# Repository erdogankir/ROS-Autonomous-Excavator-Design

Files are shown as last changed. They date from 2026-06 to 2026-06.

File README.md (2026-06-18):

# Teleoperation-Assisted Autonomous Excavator Design & Modeling 🚜🤖

This repository contains the complete conceptual design, kinematic modeling, ROS-based autonomous algorithms, and embedded systems architecture for a teleoperation-assisted autonomous excavator.

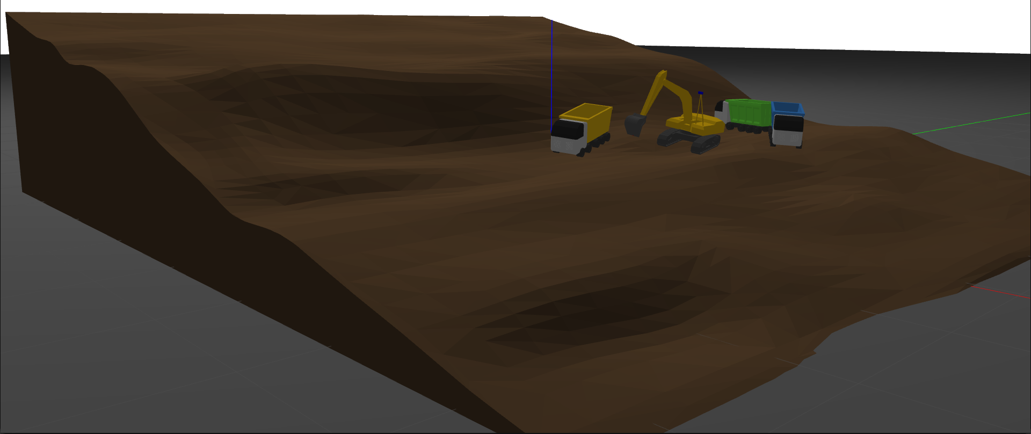
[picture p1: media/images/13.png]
Gazebo Terrain & Target Truck


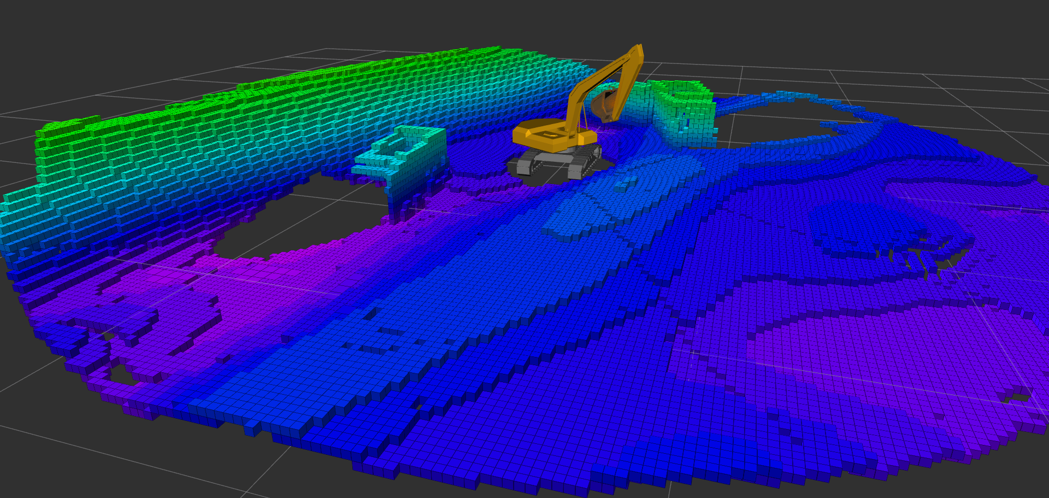
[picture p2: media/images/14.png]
RViz OctoMap Volumetric Mapping


## 🎯 Project Overview
In industries with harsh and hazardous environments like mining and construction, minimizing human exposure while maximizing operational efficiency is a critical engineering challenge. This project aims to transform traditional heavy machinery into smart, situational-aware systems. By developing a digital twin of a CAT 349E excavator, the system achieved an 84% operational success rate in end-to-end autonomous dig-and-load cycles across 100 simulation trials. 

## ⚙️ Technical Specifications
* **Simulation Environment:** ROS Noetic & Gazebo (ODE Physics Engine)
* **Base Model:** 1:10 scaled Caterpillar 349E excavator
* **Perception:** Dual RGB-D Depth Cameras (640x480 VGA, 10Hz)
* **Hardware Prototyping:** Dual-Core ESP32 microcontroller with PCA9685 PWM driver and DRV8833 H-Bridges
* **Actuators:** N20 DC Gearmotors (50 RPM for torque, 1000 RPM for linear actuators)
* **Power Management:** 7.4V 2S Li-ion battery (2450 mAh) managed by a 13A BMS

## 🔬 Engineering Methodology & Algorithms
All simulation and autonomous control phases were executed using **ROS Noetic**, while the physical prototype was driven by custom C++ embedded firmware. The engineering workflow includes:

1. **Kinematic Modeling:** The 4-DOF manipulator (swing, boom, arm, bucket) was mapped using URDF. Inverse kinematics were solved numerically via the MoveIt! framework and KDL library to avoid singularity states.
2. **3D Perception & Mapping:** Point Cloud data from RGB-D sensors were converted into volumetric maps using the OctoMap algorithm to scan dynamic terrains.
3. **Computer Vision:** Target truck localization was achieved dynamically using HSV color space masking and image moments via OpenCV.
4. **Trajectory Generation:** To eliminate mechanical jerks during operations, a custom Cosine Interpolation (S-Curve) motor was developed for smooth acceleration.
5. **Hardware Proof of Concept:** A 6-axis open-loop physical prototype was manufactured, featuring low-latency teleoperation controlled by a Sony DualSense gamepad over Wi-Fi/Bluetooth.

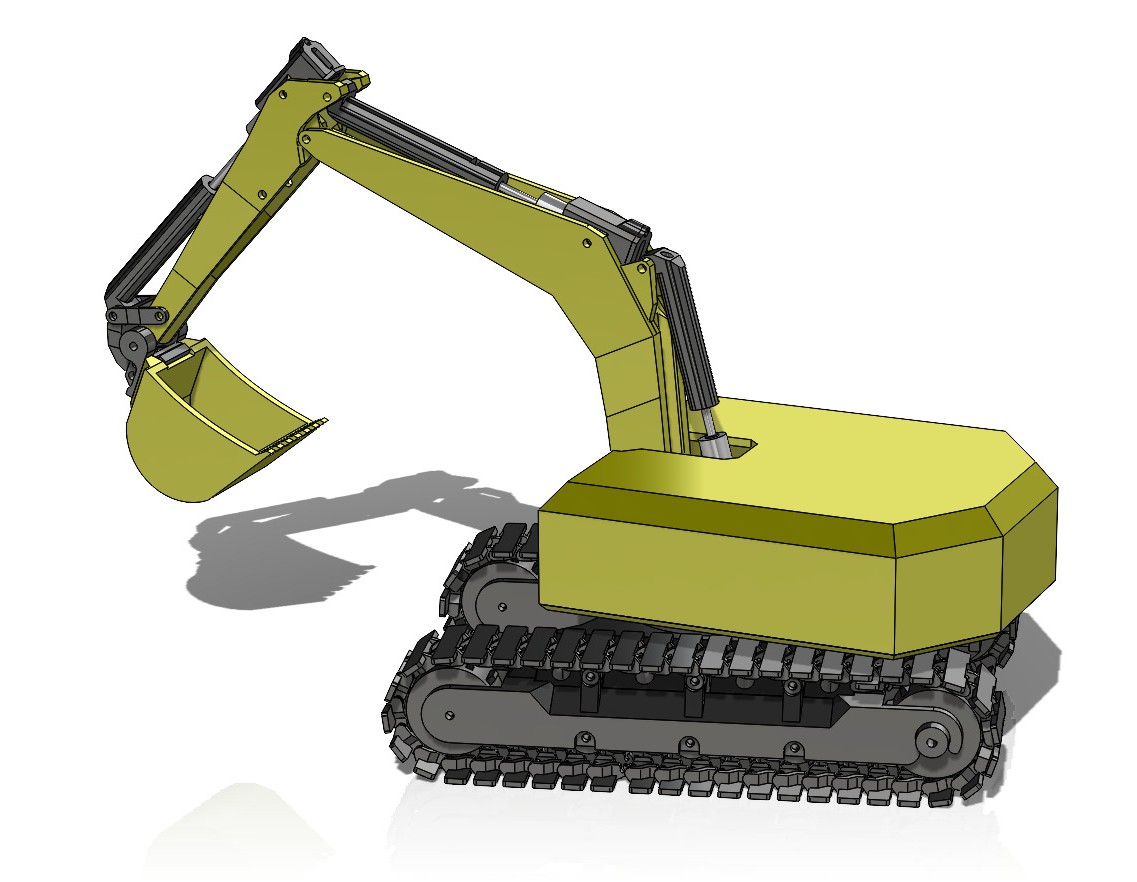
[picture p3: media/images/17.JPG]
PCAD Prototype


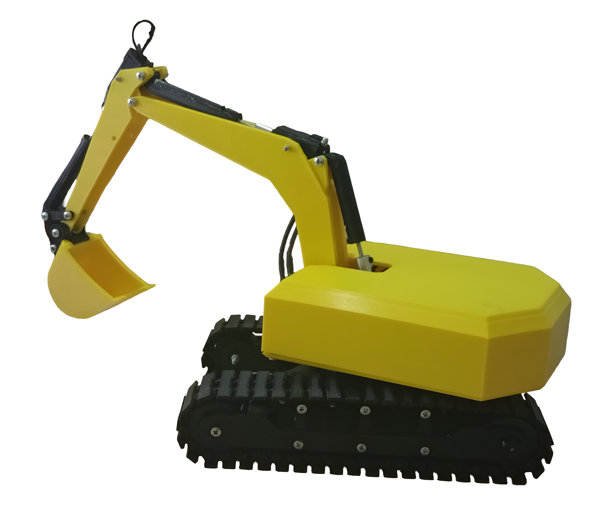
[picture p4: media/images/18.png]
Physical Prototype


## 📂 Repository Structure
* `/ros_workspace`: Contains ROS Noetic packages, Gazebo simulation environments, URDF models, MoveIt! configurations, and Python/OpenCV autonomy scripts.
* `/embedded_systems`: PlatformIO-based C++ source code for ESP32 teleoperation and motor driver control logic.
* `/cad_files`: SolidWorks native files and exported .STEP/.STL files for 3D printing of the 1:10 scale physical prototype.
* `/documents`: Comprehensive engineering design report (in Turkish) detailing dynamic equations, electrical schematics, and simulation outputs.
* `/media`: Contains project videos and high-resolution images demonstrating the Gazebo simulation and the physical prototype in action.

## 🛠 Dependencies
To compile this project in the ROS environment and run the autonomous cycles, the following system requirements must be installed:

**ROS & Simulation Side:**
* ROS Noetic Ninjemys (Ubuntu 20.04)
* Gazebo 11 (ODE Physics Engine)
* MoveIt! and KDL Library (`ros-noetic-moveit`)
* OctoMap 3D Mapping (`ros-noetic-octomap`, `ros-noetic-octomap-rviz-plugins`)
* OpenCV Vision Library (`ros-noetic-vision-opencv`)

**Embedded Systems Side (ESP32):**
* PlatformIO IDE
* ESP32 Board Packages
* Adafruit PCA9685 PWM Driver Library

## 🚀 Installation Instructions

**1. Compiling the ROS Workspace:**
```bash
mkdir -p ~/catkin_ws/src
cd ~/catkin_ws/src
git clone [https://github.com/erdogankir/ROS-Autonomous-Excavator-Design.git](https://github.com/erdogankir/ROS-Autonomous-Excavator-Design.git)
cd ..
rosdep install --from-paths src --ignore-src -r -y
catkin_make
source devel/setup.bash
```

**2. Flashing the Embedded Firmware:**
* Open the `/embedded_systems/esp32_teleop` directory with VS Code (PlatformIO).
* Connect the ESP32 to your computer via USB.
* Compile and upload using the `Upload` button in PlatformIO.

## 📌 Version and Commit Info
* **Release Matching the Final Report:** [v1.0.0 - Final Report Release](https://github.com/erdogankir/ROS-Autonomous-Excavator-Design/releases/tag/v1.0.0)
* The operational tests presented in the June 2026 graduation report were conducted on this specific version (commit).

## 📄 License and Access
* **License:** Non-Commercial Use Only, Sharing With Attribution, Remix Culture Allowed
* **Last Access Date:** June 17, 2026

---
*Designed by Erdoğan Kır as a senior Mechatronics Engineering design project.*

---
# Teleoperasyon Destekli Otonom Ekskavatör Tasarımı ve Modellemesi 🚜🤖

Bu depo, teleoperasyon destekli otonom bir ekskavatöre ait kavramsal tasarım, kinematik modelleme, ROS tabanlı otonom algoritmalar ve gömülü sistem mimarisini içermektedir.

Gazebo Terrain & Target Truck

RViz OctoMap Volumetric Mapping

## 🎯 Proje Özeti
Madencilik ve inşaat gibi zorlu saha koşullarına sahip sektörlerde, operasyonel verimliliği maksimize ederken insan riskini minimize etmek kritik bir mühendislik hedefidir. Bu proje, geleneksel ağır iş makinelerini çevresel farkındalığa sahip akıllı sistemlere dönüştürmeyi amaçlamaktadır. CAT 349E ekskavatörünün dijital ikizi geliştirilmiş ve sistem, 100 simülasyon denemesinde uçtan uca otonom kazı-yükleme döngülerinde %84 operasyonel başarı oranına ulaşmıştır.

## ⚙️ Teknik Özellikler
* **Simülasyon Ortamı:** ROS Noetic ve Gazebo (ODE Fizik Motoru)
* **Referans Model:** 1:10 ölçekli Caterpillar 349E ekskavatör
* **Algılayıcılar:** Çift RGB-D Derinlik Kamerası (640x480 VGA, 10Hz)
* **Donanım Prototipi:** PCA9685 PWM sürücü ve DRV8833 köprülerine sahip Çift Çekirdekli ESP32 mikrodenetleyici
* **Aktüatörler:** N20 Redüktörlü DC Motorlar (Tork için 50 RPM, lineer aktüatörler için 1000 RPM)
* **Güç Yönetimi:** 13A BMS ile yönetilen 7.4V 2S Li-ion batarya (2450 mAh)

## 🔬 Mühendislik Metodolojisi ve Algoritmalar
Tüm simülasyon ve otonom kontrol aşamaları **ROS Noetic** kullanılarak gerçekleştirilmiş, fiziksel prototip ise özel C++ gömülü yazılımlarla sürülmüştür. Mühendislik iş akışı şunları içerir:

1. **Kinematik Modelleme:** 4 serbestlik dereceli manipülatör (kule, bom, arm, kova) URDF kullanılarak modellenmiştir. Ters kinematik hesaplamaları, tekillik (singularity) durumlarından kaçınmak için MoveIt! ve KDL kütüphanesi ile nümerik olarak çözülmüştür.
2. **3B Algılama ve Haritalama:** Dinamik arazileri taramak için RGB-D sensörlerden gelen Nokta Bulutu (Point Cloud) verileri, OctoMap algoritması kullanılarak hacimsel haritalara dönüştürülmüştür.
3. **Bilgisayarlı Görü:** Hedef kamyonun dinamik tespiti, OpenCV üzerinden HSV renk uzayı maskelemesi ve görüntü momentleri (image moments) kullanılarak sağlanmıştır.
4. **Yörünge Planlaması:** Operasyonlar sırasında mekanik sarsıntıları önlemek ve ivmelenmeyi yumuşatmak için Kosinüs İnterpolasyon (S-Curve) motoru geliştirilmiştir.
5. **Donanımsal İspat (Proof of Concept):** Wi-Fi/Bluetooth üzerinden Sony DualSense oyun kumandası ile kontrol edilen, düşük gecikmeli teleoperasyon yeteneğine sahip 6 eksenli açık çevrim bir fiziksel prototip üretilmiştir.

PCAD Prototype

Physical Prototype

## 📂 Depo Yapısı
* `/ros_workspace`: ROS Noetic paketlerini, Gazebo simülasyon ortamlarını, URDF modellerini, MoveIt! yapılandırmalarını ve Python/OpenCV otonomi algoritmalarını içerir.
* `/embedded_systems`: ESP32 teleoperasyon ve motor sürücü kontrol mantığı için PlatformIO tabanlı C++ kaynak kodları.
* `/cad_files`: 1:10 ölçekli fiziksel prototipin 3B basımı için SolidWorks yerel parça dosyaları ve dışa aktarılmış .STEP/.STL dosyaları.
* `/documents`: Dinamik denklemleri, elektronik şemaları ve simülasyon çıktılarını detaylandıran kapsamlı mühendislik bitirme raporu.
* `/media`: Gazebo simülasyonunu ve fiziksel prototipin çalışmasını gösteren proje videolarını ve yüksek çözünürlüklü görselleri içerir.

## 🛠 Bağımlılıklar
Bu projeyi ROS ortamında derleyebilmek ve otonom döngüleri çalıştırabilmek için aşağıdaki sistem gereksinimlerinin kurulu olması gerekmektedir:

**ROS & Simülasyon Tarafı:**
* ROS Noetic Ninjemys (Ubuntu 20.04)
* Gazebo 11 (ODE Fizik Motoru)
* MoveIt! ve KDL Kütüphanesi (`ros-noetic-moveit`)
* OctoMap 3B Haritalama (`ros-noetic-octomap`, `ros-noetic-octomap-rviz-plugins`)
* OpenCV Görüntü İşleme Kütüphanesi (`ros-noetic-vision-opencv`)

**Gömülü Sistem Tarafı:**
* PlatformIO IDE
* ESP32 Board Paketleri
* Adafruit PCA9685 PWM Sürücü Kütüphanesi

## 🚀 Kurulum Talimatları

**1. ROS Çalışma Alanının Derlenmesi:**
```bash
mkdir -p ~/catkin_ws/src
cd ~/catkin_ws/src
git clone [https://github.com/erdogankir/ROS-Autonomous-Excavator-Design.git](https://github.com/erdogankir/ROS-Autonomous-Excavator-Design.git)
cd ..
rosdep install --from-paths src --ignore-src -r -y
catkin_make
source devel/setup.bash
```

**2. Gömülü Yazılımın Flaşlanması:**
* `/embedded_systems/esp32_teleop` dizinini VS Code (PlatformIO) ile açın.
* ESP32'yi USB üzerinden bilgisayara bağlayın.
* PlatformIO üzerinden `Upload` butonu ile derleyip yükleyin.

## 📌 Sürüm ve Commit Bilgisi
* **Raporla Eşleşen Sabit Sürüm:** [v1.0.0 - Bitirme Raporu Sürümü](https://github.com/erdogankir/ROS-Autonomous-Excavator-Design/releases/tag/v1.0.0)
* Haziran 2026'da sunulan bitirme raporundaki operasyonel testler bu sürüm (commit) üzerinden gerçekleştirilmiştir.

## 📄 Lisans ve Erişim
* **Lisans:** Sadece Ticari Olmayan Kullanım, Kaynak Belirtmek Şartıyla Paylaşım, Remix Kültürü İzni
* **Son Erişim Tarihi:** 17 Haziran 2026

---
*Mekatronik Mühendisliği bitirme projesi olarak Erdoğan Kır tarafından tasarlanmıştır.*

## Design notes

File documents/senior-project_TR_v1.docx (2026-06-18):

T.C.

SAKARYA UYGULAMALI BİLİMLER ÜNİVERSİTESİ
TEKNOLOJİ FAKÜLTESİ

MEKATRONİK MÜHENDİSLİĞİ BÖLÜMÜ

TELEOPERASYON DESTEKLİ OTONOM EKSKAVATÖR TASARIMI VE MODELLEMESİ

Bitirme Çalışması Raporu

G180918066 Erdoğan KIR

Danışmanı | : | Doç. Dr. Gökhan ATALI

Haziran 2026

T.C.

SAKARYA UYGULAMALI BİLİMLER ÜNİVERSİTESİ
TEKNOLOJİ FAKÜLTESİ

MEKATRONİK MÜHENDİSLİĞİ BÖLÜMÜ

TELEOPERASYON DESTEKLİ OTONOM EKSKAVATÖR TASARIMI VE MODELLEMESİ

Bitirme Çalışması Raporu

G180918066 Erdoğan KIR

Danışmanı | : | Doç. Dr. Gökhan ATALI

Danışman | Jüri | Jüri
Doç. Dr. Gökhan ATALI | Dr. Öğr. Üyesi Muhammed Salih SARIKAYA | Arş. Gör. Eşref Şamil ZAMANOĞLU

BEYAN

Rapor içindeki tüm verilerin akademik kurallar çerçevesinde tarafımdan elde edildiğini, görsel ve yazılı tüm bilgi ve sonuçların akademik ve etik kurallara uygun şekilde sunulduğunu, kullanılan verilerde herhangi bir tahrifat yapılmadığını, başkalarının eserlerinden yararlanılması durumunda bilimsel normlara uygun olarak atıfta bulunulduğunu, raporda yer alan verilerin bu üniversite veya başka bir üniversitede herhangi bir çalışmada kullanılmadığını beyan ederim.

Erdoğan KIR

08.06.2026

YAPAY ZEKA KULLANIM BEYANI

Bu bitirme çalışmasının yazım, yapılandırma ve editoryal okuma aşamalarında dilbilgisi kontrolleri ve metin akışının iyileştirilmesi amacıyla Google Gemini büyük dil modelinden destek alınmıştır. Raporda sunulan tüm mühendislik tasarımları tamamen araştırmacının kendi özgün çalışmaları olup, teknik veriler birincil literatür kaynaklarıyla desteklenmiştir.

Erdoğan KIR

15.06.2026

# TEŞEKKÜR

Lisans eğitimim boyunca benden maddi ve manevi desteklerini esirgemeyen, her türlü zorlukta yanımda duran ve bu günlere gelmemde en büyük pay sahibi olan kıymetli aileme minnettarım.

# İÇİNDEKİLER

# SİMGELER VE KISALTMALAR

3B | : 3 Boyutlu
3D | : 3 Dimensional
5G | : 5th Generation
BMS | : Battery Management System
BOM | : Bill of Materials
C_x | : Görüntü Momenti
C(Θ,Θ) | : Coriolis ve merkezkaç kuvvetleri
CAD | : Computer Aided Design
CAT | : Caterpillar (Incorporated)
CE | : Construction Equipment
COG | : Center of Gravity
D | : Çap
D-H | : Denavit-Hartenberg
dk | : Dakika
DOF | : Degree of Freedom
ESP | : Espressif Systems
EV | : Electric Vehicle
F_(silindir) | : Hidrolik İtme Kuvveti
FEA | : Finite Element Analysis
G(Θ) | : Yerçekimi vektörü
HMI | : Human-Machine Interface
HSV | : Hue-Saturation-Value
Hz | : Hertz
I_(xx) | : Inertia Matrisi
IK | : Inverse Kinematic
J^T (Θ)F_(ext) | : Tork Direnci Matrisi
KDL | : Kinematics and Dynamics Library
kN | : KiloNewton
kPa | : KiloPascal
L | : Litre
Li-ion | : Lithium-ion
Li-Po | : Lithium-polyme
LOS | : Line-of-Sight – LOS
M_(xx) | : Piksel Matrisi Ağırlık Merkezi
M(Θ) | : Atalet ve kütle matrisi
m | : Metre
MPa | : Megapascal
ODE | : Open Dynamics Engine
P | : Pressure
PETG | : Polyethylene Terephthalate Glycol
PID | : Proportional-Integral-Derivative
PLA | : Polylactic Acid
PWM | : Pulse Width Modulation
® | : Registered Trademark
R | : Rotate
rad | : Radyan
RC | : Radio Controlled
RF | : Radio Frequency
RGB | : Red-Green-Blue
RGB-D | : Red-Green-Blue-Depth
ROS | : Robot Operating System
RViz | : Robot Visualizer
SLAM | : Simultaneous Localization and Mapping
T_i^(i-1) | : Homojen Dönüşüm Matrisi
TCP | : Tool Center Point
URDF | : Unified Robot Description Format
VP | : Virtual Prototyping
Wi-Fi | : Wireless Fidelity
Xacro | : Extensible Markup Language Macro
XML | : Extensible Markup Language
YOLO | : You Only Look Once (Object Detection Algorithm)

# ŞEKİLLER LİSTESİ

# TABLOLAR LİSTESİ

# ÖZET

Anahtar kelimeler: Otonom Ekskavatör, ROS, Gazebo Simülasyonu, Teleoperasyon, ESP32, Sensör Füzyonu.

Bu çalışma, Sakarya Uygulamalı Bilimler Üniversitesi kapsamında yürütülen, inşaat sahalarında güvenliği ve verimliliği artırmayı hedefleyen "Teleoperasyon Destekli Otonom Ekskavatör Tasarımı ve Modellemesi" projesinin nihai sonuçlarını sunmaktadır. Proje kapsamında, endüstriyel bir ekskavatörün ROS (Robot Operating System) tabanlı simülasyon ortamında kinematik modellemesi, çevresel algılama (SLAM ve 3D Haritalama), nesne tanıma ve otonom kaz-yükle döngülerinin planlanması süreçleri uçtan uca gerçekleştirilmiştir.

Geliştirilen otonom mimarinin kararlılığını test etmek amacıyla Gazebo fizik motoru üzerinde 100 ardışık bağımsız simülasyon denemesi yapılmıştır. Uçtan uca otonom kazı ve döküm işlemlerinin gerçekleştirildiği bu denemelerde 84 başarılı ve 16 başarısız görev kaydedilmiş olup, sistem %84 operasyonel başarı oranına ulaşmıştır. Başarılı görevlerde ortalama çevrim süresi 4 dakika 9 saniye, asgari çevrim süresi 3 dakika 13 saniye ve azami çevrim süresi 5 dakika 44 saniye olarak ölçülmüştür.

Simülasyon doğrulamasının yanı sıra, ESP32 ve DualSense tabanlı 6 eksenli açık çevrim bir fiziksel ekskavatör prototipi üretilmiş, teleoperasyon konseptinin donanımsal ispatı (Proof of Concept) başarıyla test edilmiştir. Çalışma kapsamında otonom algoritmalar yalnızca Gazebo simülasyon ortamında koşturulmuş olup, üretilen fiziksel prototip üzerinde herhangi bir otonom sürüş veya kazı işlemi gerçekleştirilmemiştir; fiziksel sistem tamamen uzaktan kontrol (teleoperasyon) testleri ile sınırlandırılmıştır. Sistemin operasyonel otonomisi; mobil yürüyüş platformunda otonominin bulunmaması , hedef taşıyıcının manipülatör erişim zarfı içinde kalma zorunluluğu ve çevresel sensör görüş hattı (LOS) kısıtlamaları gibi temel sınırlılıklar altında değerlendirilmiştir.

# ABSTRACT

Keywords: Autonomous Excavator, ROS, Gazebo Simulation, Teleoperation, ESP32, Sensor Fusion.

This study presents the final outcomes of the project titled "Design and Modeling of a Teleoperation-Assisted Autonomous Excavator," conducted within Sakarya Applied Sciences University, aiming to enhance safety and efficiency at construction sites. Within the scope of the project, kinematic modeling, environmental perception (SLAM and 3D Mapping), object recognition, and autonomous dig-and-load cycle planning of an industrial excavator were implemented end-to-end in a ROS (Robot Operating System) based simulation environment.

To evaluate the stability of the developed autonomous architecture, 100 consecutive independent simulation trials were conducted on the Gazebo physics engine. In these trials where end-to-end autonomous excavation and dumping operations were executed, 84 successful and 16 failed tasks were recorded, achieving an operational success rate of 84%. For the successful tasks, the average cycle time was measured as 4 minutes 9 seconds, with a minimum cycle time of 3 minutes 13 seconds and a maximum cycle time of 5 minutes 44 seconds.

In addition to the simulation validation, an ESP32 and DualSense-based 6-axis open-loop physical excavator prototype was manufactured, and the hardware proof of concept for the teleoperation framework was successfully verified. The operational autonomy of the system was evaluated under fundamental constraints, such as the absence of autonomy on the mobile tracks, the necessity for the target vehicle to remain within the manipulator’s workspace reach envelope, and environmental line-of-sight (LOS) sensor limitations.

# BÖLÜM 1. GİRİŞ

Gelişen teknoloji ve Endüstri 4.0 devrimi, geleneksel üretim ve inşaat yöntemlerini köklü bir değişime zorlamaktadır. Özellikle madencilik, inşaat ve tehlikeli atık yönetimi gibi zorlu saha koşullarına sahip sektörlerde, insan faktöründen kaynaklanan iş kazalarını minimize etmek ve operasyonel verimliliği maksimize etmek temel bir mühendislik hedefi haline gelmiştir. Bu dönüşümün en kritik yapı taşlarından biri, ağır iş makinelerinin teleoperasyon (uzaktan kontrol) ve otonom sistemlerle donatılarak akıllı makinelere dönüştürülmesidir.

Bu çalışmanın temel amacı, endüstriyel standartlarda (Caterpillar 349E ekskavatör modeli referans alınarak) bir ağır iş makinesinin kinematik ve dinamik analizlerini gerçekleştirmek; ardından Robot İşletim Sistemi (ROS) altyapısı kullanılarak teleoperasyon destekli ve otonom kazı-yükleme döngüleri yapabilen bir sistem mimarisi tasarlamaktır.

## 1.1. Çalışmanın Önemi ve Sektörel Katkısı

İş makineleri sektörü, yapısı gereği yüksek hata toleranssızlığına sahip bir alandır. Yorgunluk, dikkat dağınıklığı veya çevresel görüş kısıtlamaları (kör noktalar, toz, titreşim vb.), operatör performansını düşürmenin yanı sıra ölümcül kazalara zemin hazırlamaktadır. Otonom ekskavatör sistemleri, tekrar eden kazı-boşaltma (trenching and dumping) döngülerini yüksek hassasiyetle ve yorulmaksızın gerçekleştirerek proje sürelerini ciddi oranda kısaltır.

Ayrıca, radyoaktif alanlar, göçük riski taşıyan madenler veya doğal afet sonrası enkaz bölgeleri gibi insan hayatının riske atılamayacağı durumlarda, makinenin güvenli bir merkezden "teleoperasyon" ile yönetilmesi, modern mekatronik mühendisliğinin en hayati uygulama alanlarından biridir. Bu proje, sensör füzyonu (RGB derinlik kameraları) kullanılarak çevresel farkındalık (situational awareness) kazandırılmış bir ekskavatörün, karmaşık topografyalarda nasıl karar verebildiğini ortaya koymaktadır.

## 1.2. Temel Kavramlar

Projenin altyapısını oluşturan ana mühendislik konseptleri aşağıda tanımlanmıştır:

- Otonom Sistemler (Autonomous Systems): Çevresel verileri sensörler aracılığıyla algılayan, bu verileri işleyerek bağımsız karar alabilen ve dışarıdan bir insan müdahalesi olmaksızın kendisine verilen görevi icra eden sistemlerdir.
- Teleoperasyon (Teleoperation): Bir makinenin veya robotik sistemin, iletişim protokolleri (RF, Wi-Fi, 5G vb.) kullanılarak uzak bir mesafeden bir operatör tarafından gerçek zamanlı olarak kontrol edilmesidir. Master-Slave (Yöneten-Yönetilen) mimarisine dayanır.
- Robotik Kinematik: Birbirine eklemlerle bağlı rijit cisimlerin (boom, arm, kova), bunlara etki eden kuvvetler dikkate alınmaksızın, uzaydaki hareketlerinin ve konumlarının geometrik olarak incelenmesidir. Ters kinematik analizleri, kepçe ucunun istenilen X, Y, Z koordinatlarına ulaşması için eklem açılarının ne olması gerektiğini hesaplar.

# BÖLÜM 2. ÖNCEKİ ÇALIŞMALARIN ARAŞTIRILMASI

Otonom ağır vasıta ve iş makineleri üzerine yapılan çalışmalar, donanımsal yetersizliklerin aşılmasıyla birlikte son on yılda ivme kazanmış; hem endüstriyel Ar-Ge merkezlerinin hem de akademik literatürün odak noktası haline gelmiştir. Bu bölümde, alandaki öncü endüstriyel çözümler ile akademik araştırmalar; kullanılan yöntemler, entegre edilen sistemler, elde edilen sonuçlar ve mevcut sınırlılıklar bağlamında karşılaştırmalı olarak incelenmiştir.

## 2.1. Endüstriyel Çalışmalar ve Teknolojik Altyapılar

Küresel pazardaki öncü şirketler, kapalı çevrim donanımlar ve yüksek bütçeli altyapılar ile şantiye otonomisine yaklaşmaktadır:

- Caterpillar (Cat® Command): Operatörlerin binlerce kilometre öteden sanal kokpitler aracılığıyla birden fazla iş makinesini yönetmesini sağlayan bir teleoperasyon yöntemi kullanır. Sonuç olarak yüksek operasyonel verim ve güvenlik elde edilse de, sistemin sınırlılığı tamamen tescilli (proprietary) kapalı bir mimari olması ve otonomiden ziyade insan faktörüne (teleoperasyon) bağımlı çalışmasıdır (Caterpillar Inc., 2015).
- Komatsu (Smart Construction): Yapay zeka ve dron haritalama yöntemlerini kullanarak sahanın dijital ikizini (digital twin) oluşturur. Bu sayede ekskavatörler otonom kazı derinliği ayarı yapabilir. Ancak bu mimarinin en büyük sınırlılığı, sistemi kurmak için şantiyede devasa bir ön hazırlık ve yüksek maliyetli bulut altyapısı gerekmesidir (Komatsu Ltd., 2021).
- Volvo CE (TARA Projesi): Yöntem olarak tamamen elektrikli ve kabinsiz (operatörsüz) araç tasarımlarına odaklanmıştır. Sonuç olarak şantiye içi lojistikte sıfır karbon emisyonu başarılmıştır. Buna karşın, kompleks kazı ve kova-toprak etkileşimi gerektiren durumlarda tam otonomi henüz ticarileşememiştir (Volvo Construction Equipment, 2022).

## 2.2. Akademik Çalışmalar ve Algoritmik Yaklaşımlar

Akademik literatür, ticari kaygılardan ziyade matematiksel yörünge planlaması ve sensör optimizasyonu problemlerine odaklanmıştır:

- Zhang vd. (2021): Baidu Research bünyesinde geliştirilen AES (Autonomous Excavator System) çalışmasında, ROS tabanlı algoritmalar kullanılarak endüstriyel ekskavatörler için otonom yörünge planlaması geliştirmişlerdir. Geliştirilen sistemin sonucu, uzun saatler boyunca malzeme yükleme döngülerini dış müdahale olmaksızın başarıyla üretmesidir. Fakat dinamik şantiye topografyasının anlık değişimlerinde sistemin çarpışma önleme reaksiyonlarının hesaplama maliyeti, pratik sınırlılığını oluşturur (Zhang vd., 2021).
- Jud vd. (2019): ETH Zurich laboratuvarlarında yürütülen çalışmada, yöntem olarak gerçek zamanlı derinlik (RGB-D) sensör füzyonunu kullanarak otonom hendek kazısı algoritması önermişlerdir. Elde edilen sonuç, kazı esnasında değişen zemin geometrisine anlık tepki verilebilmesidir. En büyük sınırlılık ise tozlu veya engelli görüş hattı (LOS) durumlarında optik sensörlerin körleşmesi (oklüzyon) problemidir (Jud vd., 2019).

## 2.3. Genel Değerlendirme ve Bu Çalışmanın Literatürdeki Yeri

Mevcut endüstriyel sistemler yüksek maliyetli ve geliştiricilere kapalıyken; akademik çalışmalar genellikle sadece yazılım (simülasyon) tarafında kalmakta ve gerçek dünya entegrasyonu eksik olmaktadır. Bu çalışmada önerilen mimari; ROS Noetic tabanlı S-Curve (Kosinüs İnterpolasyonu) yörünge motoru ile Martinez'in yörünge sınırlılıklarını aşmayı hedeflerken, ESP32 ve açık çevrim donanımlar kullanılarak Caterpillar'ın kapalı teleoperasyon mantığına düşük maliyetli ve erişilebilir bir donanım (Proof of Concept) alternatifi sunmaktadır (Jud vd., 2019; Zhang vd., 2021).

# BÖLÜM 3. YÖNTEM VE TASARIM

## 3.1. URDF Tabanlı Kinematik Modelleme ve Nümerik Çözücü Altyapısı

Modern robotik sistem mimarilerinde, manipülatörlerin kinematik ve dinamik davranışlarının analitik (elle hesaplanan) denklemlerle formüle edilmesi yerine, konfigürasyon tabanlı yazılımsal modelleme standartları benimsenmektedir. Bu çalışmada, Caterpillar 349E ekskavatör modelinin 4 serbestlik dereceli (kule dönüşü, bom, arm ve kova) kinematik zinciri, ROS ekosisteminin standart robot açıklama formatı olan URDF (Unified Robot Description Format) ve XML makroları (Xacro) kullanılarak dijital ortamda modellenmiştir (Quigley vd., 2009).

URDF mimarisinde, geleneksel Denavit-Hartenberg (D-H) konvensiyonunun getirdiği statik kısıtlamalar aşılmış; her bir uzvun (link) kütle merkezi, eylemsizlik tensörleri ve eklem (joint) limitleri doğrudan yazılımsal ağaç (tree) yapısı içerisinde tanımlanmıştır. 1:10 ölçekli modelin bağlantı noktaları, kinematik kısıtları ve dönme eksenleri yazılıma esnek bir şekilde gömülmüştür.

### 3.1.1. MoveIt! ve KDL (Kinematics and Dynamics Library) Entegrasyonu

Otonom kazı algoritmalarında hedef kova ucunun kartezyen koordinatlardan anlık eklem açılarına dönüştürülmesi (Ters Kinematik - IK çözümleri), sistemin en kritik hesaplama yükünü oluşturur. Bu projede, elle hesaplanan ve tekillik durumlarında çöken analitik ters kinematik denklemleri yerine, ROS içerisindeki MoveIt! hareket planlama çerçevesi ve varsayılan kinematik çözücü olan KDL (Kinematics and Dynamics Library) entegre edilmiştir.

KDL çözücüsü, URDF dosyasından okuduğu kinematik zinciri kullanarak Newton-Raphson tabanlı nümerik iterasyon yöntemleriyle ters kinematik problemlerini çözer. Kule dönüş açısı ( θ_1 ) için hedef noktanın izdüşümü doğrudan hesaplanırken; bom, arm ve kova eklem açıları ( θ_2 ,θ_3 ,θ_4 ) saniyenin binde biri (ms) düzeyindeki sürelerde nümerik olarak yakınsanarak MoveIt! yörünge planlayıcısına aktarılır (Chitta vd., 2012). Bu yazılımsal yaklaşım, manipülatörün şantiye ortamındaki anlık engellerden kaçarken kinematik tekilliklere (singularity) düşmesini otomatik olarak engellemekte ve döngü kararlılığını maksimuma çıkarmaktadır (Chitta vd., 2012).

### 3.1.2. Makine Dinamiği ve Newton-Euler Yaklaşımı

Sadece konum değil, ekskavatör kolunun ivmelenmesi ve hareket esnasındaki atalet kuvvetlerinin hesaplanması için Newton-Euler dinamik denklemleri kullanılmıştır. CAT 349E gibi yüksek tonajlı makinelerde; bomun kendi ağırlığı, taşıdığı yük ve kova ucunda oluşan kazı direnç kuvveti ( F_c ) sisteme devasa momentler uygular.

Birinci eklemdeki (bom tabanı) toplam tahrik torku ( τ_2 ) şu genel dinamik denklem ile ifade edilir (Denklem 3.1):

τ=M(Θ)Θ+C(Θ,Θ)Θ+G(Θ)+J^T (Θ)F_(ext) (3.1)

Burada;

- M(Θ) : Atalet ve kütle matrisi,
- C(Θ,Θ) : Coriolis ve merkezkaç kuvvetleri,
- G(Θ) : Yerçekimi (Ağırlık) vektörü,
- J^T (Θ)F_(ext) : Dış kazı kuvvetlerinin (Toprak direnci) eklemlere yansıyan tork karşılığıdır.

Simülasyon ortamında makinenin devrilmeden veya titremeden durabilmesi için (ODE üzerinde) bu kütle merkezleri ve atalet momentleri (Inertia Matrisleri) hassas bir şekilde kalibre edilmiştir (Craig, 2005).

### 3.1.3. Hidrolik Tahrik ve Kuvvet İletimi

Otonom yazılımın hesapladığı eklem torklarının donanımsal karşılığı hidrolik silindirlerdir. CAT 349E sisteminde ana sistem maksimum hidrolik debisi 770 L/dk ve çalışma basıncı P≈350 bar (35,000 kPa) seviyesindedir (Caterpillar Inc., 2015).

Bom hidrolik silindirin resmî iç çapı (Bore) D≈170 mm olup, maksimum itme kuvveti ( F_(silindir) ) formülü (Denklem 3.2):

F_(silindir) =P×A=P×((π⋅D^2)/4) (3.2)

şeklinde hesaplanır. Yaklaşık 35 MPa basınca sahip bir sistemde, tek bir bom silindiri yaklaşık 794 kN (yaklaşık 80 Ton) itme kuvveti üretebilmektedir. Kova (Bucket) silindirinin mekanik bağlantısı (Linkage) sayesinde bu doğrusal kuvvet, kova ucu kazı koparma momentine dönüştürülmektedir. Simülasyon sürecindeki ivme sınırlandırmaları (S-Curve) ve tork limitleri, donanımın bu fiziksel çalışma kapasitelerine göre belirlenmiştir.

## 3.2. Otonom Sistem Mimarisi ve Simülasyon

Ağır iş makinelerinin otonomizasyon süreçlerinde karşılaşılan en büyük engel, dinamik saha topografyası ile manipülatör kinematiği arasındaki doğrusal olmayan (non-linear) ilişkilerdir. Bu çalışmada tasarlanan otonom sistem mimarisi; çevresel algı (perception), uzaysal haritalandırma (3D mapping), bilgisayarlı görü tabanlı nesne lokalizasyonu ve adaptif yörünge planlaması (adaptive trajectory generation) katmanlarının uçtan uca (end-to-end) entegrasyonunu içermektedir. Geliştirilen bu mimari, karmaşık ve deterministik olmayan şantiye ortamlarında deterministik hareket çıktıları üretebilecek şekilde formüle edilmiştir.

### 3.2.1. Sanal Prototipleme ve Geliştirme Ortamı Altyapısı

Fiziksel dünya simülasyonu için, rijit cisim dinamiklerini ve kontak mekaniğini gerçeğe en yakın şekilde modelleyebilen ODE (Open Dynamics Engine) tabanlı Gazebo simülatörü kullanılmıştır. Projenin paralelde yürütülen Robot İşletim Sistemi (ROS) öğrenme ve geliştirme fazlarında, gerçek dünya boyutlarındaki (50 ton sınıfı) Caterpillar 349E ekskavatör modelinin Gazebo fizik motoru üzerinde yaratacağı yüksek hesaplama yükünü ve olası kontak tekilliklerini (singularity) minimize etmek amacıyla 1:10 oranında geometrik ölçeklendirme metodolojisi benimsenmiştir (Quigley vd., 2009).Bu doğrultuda, sistemin kinematik zinciri ve URDF yapısı 1:10 ölçekte küçültülmüş; dinamik kararlılığı, zemin sürtünme etkileşimlerini ve PID kontrolörlerin kararlı çalışmasını optimize etmek adına toplam simülasyon kütlesi 194,89 kg olarak tekleştirilmiştir. URDF modelinde tanımlanan bu ölçekli kütle dağılımı ve her bir rijit uzva ait köşegen atalet matrisi ( I_(xx) ,I_(yy) ,I_(zz) ) bileşenleri Tablo 3.2'de detaylandırılmıştır:

Tablo 3.2. 1:10 Ölçekli Simülasyon Modelinin (URDF) Rijit Uzuv Kütle ve Atalet Dağılımı

Uzuv Tanımı (Link Name) | Ölçekli Kütle (kg) | Ana Eksen Atalet Momentleri (Ixx,Iyy,Izz) [kg⋅m2] | Açıklama / Fonksiyon
base_link (Alt Şasi & Paletler) | 117,69 | I_(xx) =0.823 I_(yy) =0.839 I_(zz) =1.567 | Toplam kütlenin %50'sidir. Gazebo'da alt şasi eylemsizliğini ve zemin temas stabilitesini sağlar.
link_1 (Üst Kule & Kabin) | 66,76 | I_(xx) =0.31 I_(yy) =0.243 I_(zz) =0.539 | Üst kule dönüş (swing) hareketinin atalet momentini belirleyen ana kütle grubudur.
link_2 (Bom) | 6,26 | I_(xx) =0.011 I_(yy) =0.195 I_(zz) =0.203 | 1:10 ölçekli ana kaldırıcı mekanizmadır; MoveIt! yörünge tork hesaplarına direnç oluşturur.
link_3 (Arm / Kepçe Kolu) | 3,04 | I_(xx) =0.002 I_(yy) =0.041 I_(zz) =0.042 | Kazıcı ucu taşıyan ara mafsal uzvudur; penetrasyon kuvvetlerinin aktarımından sorumludur.

Tablo 3.2. (Devamı)

link_4 (Kova / Uç İşlevci) | 1,14 | I_(xx) =0.003 I_(yy) =0.002 I_(zz) =0.004 | Toprak-kova etkileşim kuvvetlerinin (contact forces) simüle edildiği uç işlevci uzvudur.
Toplam Model Kütlesi | 194,89 | — | 1:10 Ölçeklendirilmiş Kararlı Simülasyon Kütlesi

Sisteme ait temel geometrik modellerin ve bu modellerin nokta bulutu (Point Cloud) doğrulamalarının sanal ortamdaki ilk yerleşimleri Şekil 3.1 ve Şekil 3.2'de sunulmuştur.

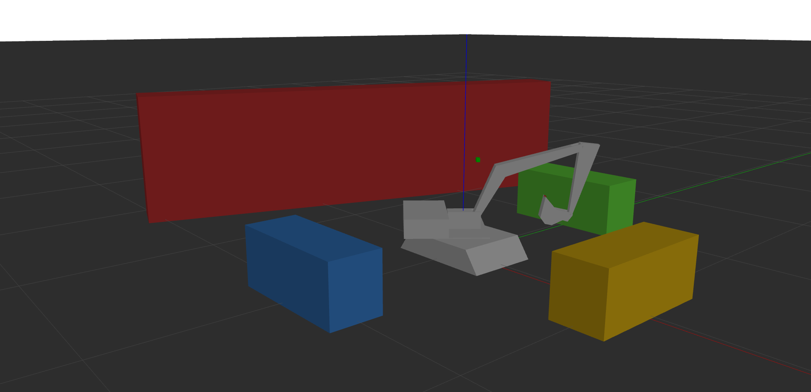
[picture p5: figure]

Şekil 3.1. Gazebo ortamında temel geometrik objelerin simülasyona aktarılması ve referans konumlandırma.

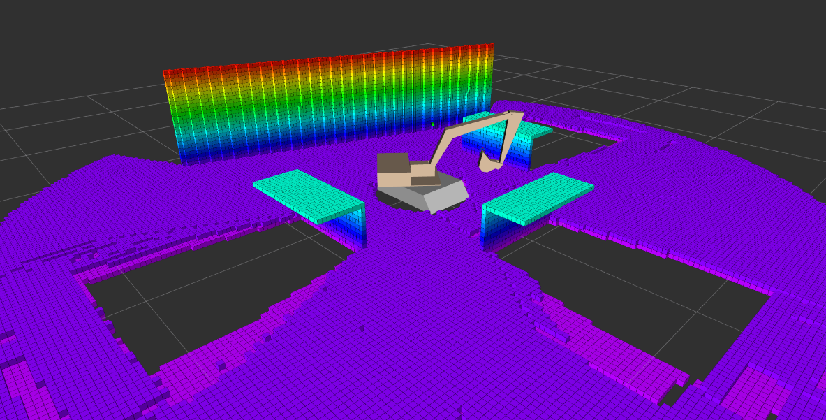
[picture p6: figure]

Şekil 3.2. RViz üzerinde temel objelere ait Point Cloud (Nokta Bulutu) derinlik verilerinin görselleştirilmesi.

### 3.2.2. Çevresel Algı ve Sensör Füzyonu Tabanlı Haritalandırma

Sisteme çevresel farkındalık (situational awareness) kazandırmak amacıyla, manipülatör üzerine yerleştirilen çift derinlik sensörü mimarisi (Dual RGB-D Sensor Fusion) geliştirilmiştir. Literatürde "kamera görüş alanı kısıtlaması ve sensör gölgelenmesi (oklüzyon)" olarak bilinen kör nokta sorununu çözmek için, kule üzerindeki "kamera_on" ve 45 derecelik düşey açıyla (Pitch: 0.785 rad) konumlandırılan "kamera_cukur" sensörleri füzyona tabi tutulmuştur.

Fiziksel bir donanımdan ziyade, Gazebo simülasyon ortamında (URDF içerisinde) eklenti (plugin) olarak tanımlanan bu RGB-D sensörlere ait teknik konfigürasyonlar ve ROS haberleşme altyapıları Tablo 3.3'te sunulmuştur.,

Tablo 3.3. Simüle Edilen RGB-D Sensör Parametreleri ve ROS Konfigürasyonları

Parametre / Spesifikasyon | Değer / Tanımlama
Sensör Tipi | Jenerik RGB-D Derinlik Kamerası (Gazebo Plugin)
Görüntü Çözünürlüğü | 640 x 480 Piksel (VGA)
Görüş Alanı (FOV) | 1.047 Radyan (~60 Derece)
Derinlik Ölçüm Menzili | 0.1 Metre (Minimum) - 10.0 Metre (Maksimum)
Yayın Frekansı (Update Rate) | 10 Hz
Birincil ROS Topic (Point Cloud) | /kamera_on/depth/points
İkincil ROS Topic (Point Cloud) | /kamera_cukur/depth/points
Referans Çerçeveleri (TF Frames) | kamera_on_link_optical, kamera_cukur_link_optical

RGB-D sensörlerden saniyede 10 Hz frekansla alınan nokta bulutu (Point Cloud) verileri, ROS tf2 dönüşüm kütüphanesi kullanılarak base_link koordinat sistemine projekte edilmekte ve 3B Voxel tabanlı OctoMap algoritmasıyla işlenmektedir (Hornung vd., 2013). Bu sayede şantiye sahasının hacimsel (volumetric) haritası oluşturulmaktadır. İş makinesi ve diğer araçların Gazebo'daki temel yerleşimi ile bu yerleşimin OctoMap haritalandırması Şekil 3.3 ve Şekil 3.4'te gösterilmiştir.

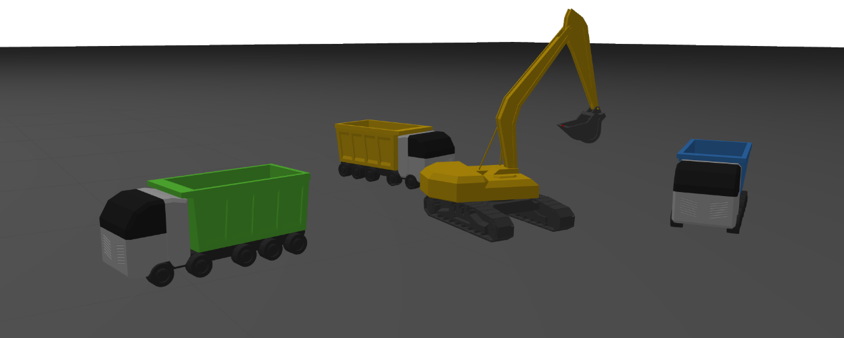
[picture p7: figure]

Şekil 3.3. İş makinesi ve hedef/aldatıcı kamyon modellerinin Gazebo çalışma düzlemine entegrasyonu.

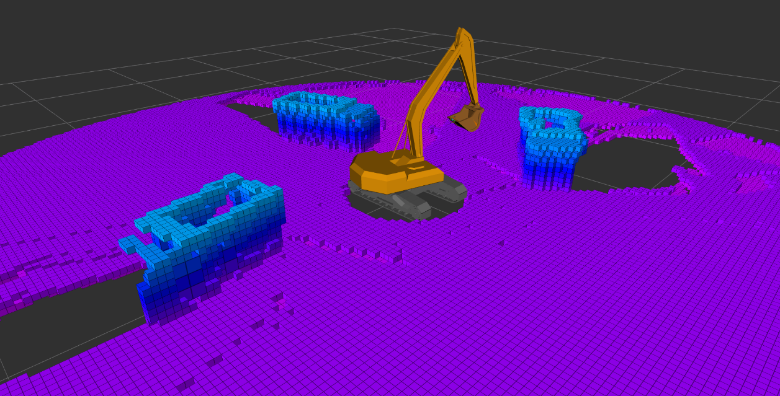
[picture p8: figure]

Şekil 3.4. Gazebo'daki araç modellerinin OctoMap algoritması ile 3B hacimsel haritalandırılması.

### 3.2.3. Bilgisayarlı Görü Tabanlı Nesne Tespiti ve Kamyon Lokalizasyonu

Ekskavatörün kazı sonrası döküm yapacağı hedef platformu (kamyon kasası) dinamik olarak bulabilmesi için bir bilgisayarlı görü düğümü tasarlanmıştır. Çevresel ışık değişimlerinden etkilenmemek adına HSV (Hue, Saturation, Value) renk uzayı tercih edilmiş ve anlık histogram taramalarıyla bir renk maskesi oluşturulmuştur (Bradski, 2000). Görüntü momentleri ( M_00 ,M_10 ,M_20 ) hesaplanarak nesnenin piksel matrisindeki ağırlık merkezi (C_x ,C_y ) tespit edilmektedir. Kamyonun gerçek uzaysal koordinatlarının bulunması ve derinlik sapmalarının engellenmesi için "Ortalama Filtresi" ve yoğun gürültü durumlarında devreye giren "Zirve Filtresi" kullanılarak veriler süzülmektedir.

(Not: Hedef kilitleme algoritmaları arka planda çalışmakta olup, bu işlemlerin sonuçları sistemin genel Point Cloud haritalarına entegre edilmiştir.)

### 3.2.4. Uçtan Uca Otonom Kontrol Döngüsü ve Adaptif Yörünge Planlaması

Tüm algısal verileri motor komutlarına dönüştüren ve otonom işleyişi yöneten yapı, "Sonlu Durum Makinesi" (Finite State Machine) mimarisidir. Bu algoritma aşağıdaki aşamalarla yürütülmektedir:

#### 3.2.4.1. Global Topoloji Haritalama Fazı (Pre-Scan)

Otonom döngü tetiklendiğinde makine kollarını güvenli bir konuma çeker ve hafızadaki eski verileri temizler. Kule ekseni -45° ile +45° arasında 15°'lik radyal adımlarla dönerek (Dairesel Tarama Modu) anlık çalışma sahasının topografik röntgenini çıkarır. Taranan her dilimin Z ekseni yüksekliği sisteme kaydedilir. Eğimli ve engebeli arazi topolojisinin Gazebo'ya eklenmesi, OctoMap ile taranması ve nihai şantiye sahasının 3B modeli sırasıyla Şekil 3.5, Şekil 3.6, Şekil 3.7 ve Şekil 3.8'de detaylandırılmıştır.

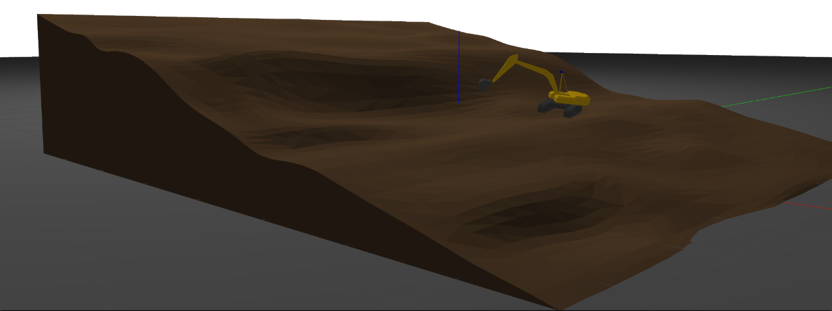
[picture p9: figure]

Şekil 3.5. Otonom kazı senaryoları için Gazebo'ya entegre edilen eğimli ve engebeli zemin topolojisi.

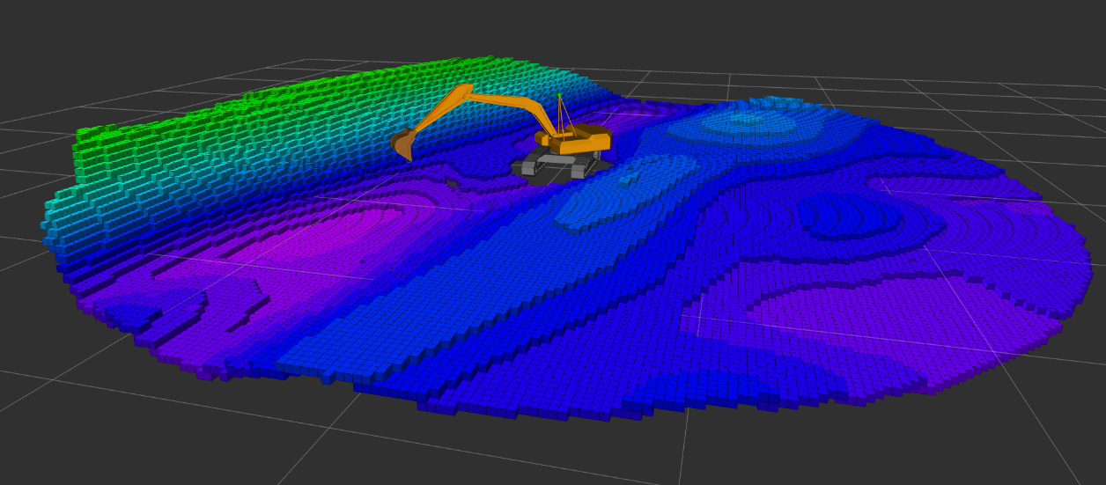
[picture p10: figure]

Şekil 3.6. Engebeli kazı sahasının RViz üzerinde voxel tabanlı OctoMap haritalandırması

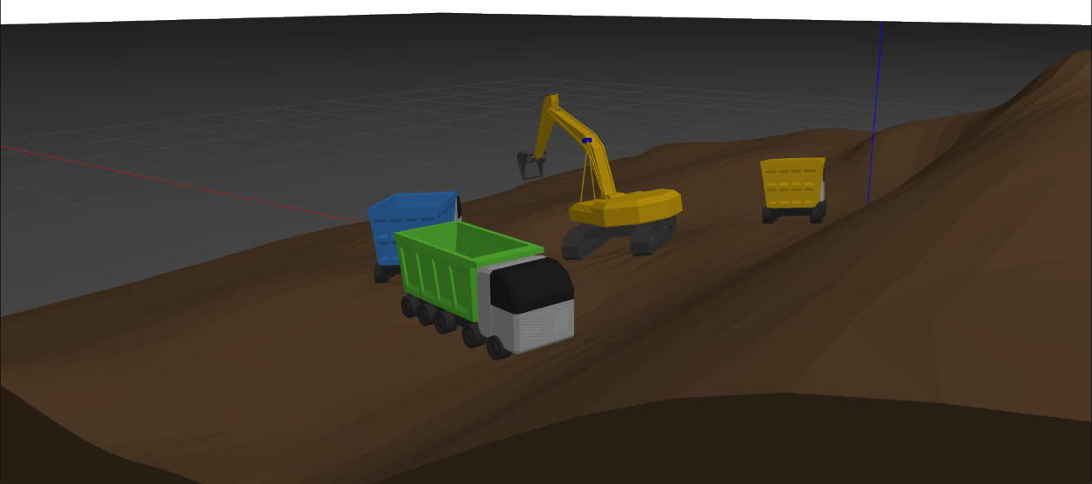
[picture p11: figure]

Şekil 3.7. Gazebo simülasyon ortamında ana şantiye sahasının ve engebeli toprak topografyasının genel görünümü.

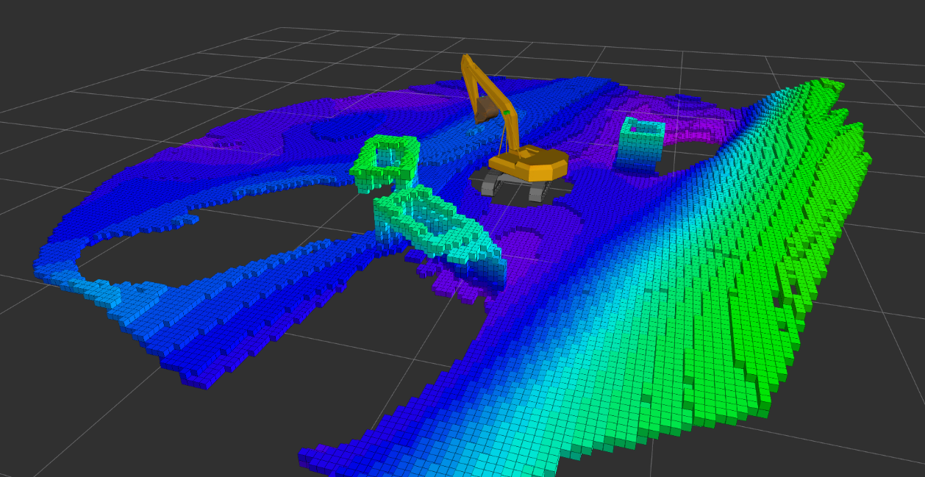
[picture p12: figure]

Şekil 3.8. Karmaşık şantiye topografyasının ve araçların nihai Point Cloud/OctoMap haritası.

#### 3.2.4.2. Adaptif Kazı ve Kosinüs İnterpolasyon Motoru

Standart hareket planlayıcılarının ürettiği lineer yörüngelerin sebep olduğu ani ivmelenme ve sarsıntıları (jerk) engellemek için trigonometrik bir Kosinüs İnterpolasyon Motoru (S-Curve) kodlanmıştır. Sistem, hafızasındaki canlı Z ekseni verisine göre Yokuş Yukarı, Yokuş Aşağı veya Düz Zemin olmak üzere 3 farklı adaptif kazı profilinden birini otonom olarak seçer. Bu yumuşak yörünge geçişi aşağıdaki formül ile hesaplanır (Denklem 3.1):

Oran=(1.0-cos(π))/2.0 (3.1)

#### 3.2.4.3. Eklem Kilitleme Tabanlı Yörünge Kısıtı ile Taşıma ve Döküm Fazı

Kazı bittikten sonra, malzemenin dökülmesini önlemek amacıyla kova eklemi (joint_4) uçuş boyunca yazılımsal olarak -3.141 radyan (Tam Kapalı) konumunda kilitlenir. PID kontrolcülerin çelişkiye düşmemesi için hız ve ivme vektörleri sıfırlanır; kamyon kasasının üzerine gelindiğinde tek kademeli süzülme eğrisi aktif edilerek hedef kasa üzerinde döküm (dumping) kinematiği başarıyla tamamlanır.

## 3.3. Gömülü Sistem Mimarisi ve Teleoperasyon Prototiplemesi

Simülasyon ortamında (Gazebo/RViz) başarıyla koşturulan otonom mimarinin donanıma aktarılması bu projenin kapsamı dışında tutulmuştur. Bunun yerine, projenin fiziksel dünyadaki uygulanabilirliğini ve insan-makine etkileşimini (HMI) test etmek amacıyla yalnızca uzaktan kontrol (teleoperasyon) yeteneğine sahip bir prototip geliştirilmiştir. Endüstriyel seviyede ROS uyumlu kapalı çevrim donanımların yüksek maliyetleri göz önüne alınarak, fiziksel prototipte otonomi hedeflenmemiş; açık çevrimli (open-loop) sistemlerle doğrudan operatör kontrollü bir donanımsal ispat (Proof of Concept) platformu inşa edilmiştir.

### 3.3.1. Tersine Mühendislik (Reverse Engineering) ve CAD Modelleme Süreci

Fiziksel prototipin mekanik şasi ve manipülatör (bom, arm, kova) bileşenlerinin tasarımında, sıfırdan bir tasarım (from-scratch design) yerine endüstriyel standartlara uygun hızlı prototipleme (rapid prototyping) metodolojisi benimsenmiştir. Bu kapsamda, ticari RC (Radio Controlled) iş makinesi modelleri ve açık kaynaklı donanım topluluklarının ("Professor Boots" vb.) paylaştığı referans tasarımlar üzerine kapsamlı bir literatür/model incelemesi yapılmıştır (Professor Boots, 2023).

Mevcut tasarımlar doğrudan kullanılmamış, form faktörü açısından (örneğin palet baklası) yalnızca referans alınmıştır. Hedeflenen donanımların şasiye entegre edilebilmesi, araç stabilitesi için iz genişliğinin artırılması ve eklem kinematiğinin CAT 349E'ye yakınsanması amacıyla tüm refrans değerlendirmeler özgün gereksinimlere göre sıfırdan projelendirilmiş ve modifiye edilmiştir. Geliştirilen CAD modelinin dijital montajı Şekil 3.9'da gösterilmiştir.


Şekil 3.9. Prototip CAD montaj görünümü

### 3.3.2. Gömülü Sistem Donanım Mimarisi ve Güç Topolojisi

Fiziksel prototip, bağımsız 6 eksenli hareket kabiliyetine (sağ/sol palet, kule dönüşü, bom, arm, kova) sahip olup, bu elektromekanik yapıyı yönetmek için modüler bir gömülü sistem mimarisi tasarlanmıştır.

Mikrodenetleyici ve Haberleşme Altyapısı: Sistemin ana beyni olarak çift çekirdekli ESP32 mikrodenetleyicisi seçilmiştir. ESP32'nin dahili Wi-Fi/Bluetooth altyapısı, sistemin DualSense gibi modern oyun kumandaları üzerinden çok düşük gecikmeyle (low-latency) teleoperasyon modunda sürülmesine olanak tanımaktadır.

Tahrik ve Sürücü Sistemleri: Çoklu motor yönetiminde mikrodenetleyicinin sinyal yükünü hafifletmek için PCA9685 (16-Kanal PWM üretici) entegresi kullanılmıştır. Fiziksel hareketler için 4 adet DRV8833 çift köprülü (H-Bridge) motor sürücü modülü tercih edilmiştir. Sistemin kinematik ve tork ihtiyaçlarına göre iki farklı redüktörlü DC motor (N20) grubu şu konfigürasyonla topolojiye dahil edilmiştir:

- Yüksek Tork Grubunda (3 adet 50 RPM): Makinenin ana kütlesini hareket ettiren sağ/sol palet sürüşlerinde ve kuleden bağımsız kararlı dönüş (swing) hareketi sağlayan kule ekseninde.
- Yüksek Hız Grubunda (3 adet 1000 RPM): Eklem torklarını doğrusal itme kuvvetine dönüştüren lineer aktüatör mekanizmalarını yüksek hızda tahrik etmek amacıyla bom, arm ve kova eklemlerinde.

Aşağıdaki tabloda motor eksenleri, devir sınıfları ve sürücü eşleşmeleri özetlenmiştir (Tablo 3.3.):

Tablo 3.3. Motor ve Sürücü Özellikleri Konfigürasyonu

Hareket Ekseni | Motor Tipi | Devir / Tork Sınıfı | Görev | Sürücü Modülü
Sağ/Sol Palet Sürüşü | N20 Redüktörlü DC | 50 RPM (Yüksek Tork) | Makine kütlesinin taşınması | DRV8833
Kule Dönüşü (Swing) | N20 Redüktörlü DC | 50 RPM (Yüksek Tork) | Bağımsız kararlı dönüş hareketi | DRV8833
Bom, Arm, Kova (Uç) | N20 Redüktörlü DC | 1000 RPM (Yüksek Hız) | Lineer aktüatör mekanizmalarının hızlı tahriki | DRV8833

Güç Yönetimi (Power Management), sistemin mobil otonomisini sağlamak için Lityum-İyon (Li-ion) hücreler kullanılmıştır. Batarya güvenliği ve dengeli şarj için BMS (Battery Management System) modülü entegre edilmiştir. Motorların anlık yüksek akım çekimlerinden kaynaklanan voltaj dalgalanmalarının (voltage drop) ESP32 üzerinde resetlenmeye yol açmaması için, lojik devreye giden hat üzerinde MP1584 (3.3V Step-Down/Buck Converter) kullanılmış ve elektriksel gürültüler (noise) seramik/elektrolitik kondansatör filtrelemeleriyle absorbe edilmiştir. Ayrıca batarya gerilimini çalışma seviyesine getirmek için Li-ion Step-Up şarj/yükseltici modüller topolojiye dahil edilmiştir. Bu bölümde kullanılan temel elektronik ve mekanik bileşenlerin özeti ve güç hattı, regülasyon ve koruma katmanlarının dağılımı aşağıdaki tablolarda özetlenmiş ve verilmiştir (Tablo 3.4.; Tablo 3.5.):

Tablo 3.4. Prototip Donanım ve Temel Malzeme Listesi

Bileşen Sınıfı | Kullanılan Donanım / Malzeme | Açıklama
Mikrodenetleyici | ESP32 Çift Çekirdekli Geliştirme Kartı | Wi-Fi/Bluetooth haberleşmesi ve ana işlemci birimi
Kontrol Arayüzü | Sony DualSense | Düşük gecikmeli teleoperasyon veri girişi
Motor Sürücü | 4 x DRV8833 Çift Köprülü Sürücü | DC motorların PWM ile sürülmesi
Sinyal Genişletici | PCA9685 (16-Kanal) | ESP32 üzerindeki PWM yükünün hafifletilmesi
Mekanik Şasi Parçaları | 3B Basım Parçalar (PLA/PETG) | Modifiye edilmiş açık kaynaklı CAD referansları

Tablo 3.5. Batarya Yönetimi ve Güç Bütçesi Dağılımı

Sistem Katmanı | Bileşen / Voltaj Regülasyonu | Sağlanan Gerilim (V) | Görev ve Koruma
Ana Güç Kaynağı | 2x Orion 15C 2450 mAh (2S Konfigürasyon) | 7.4V Nominal (8.4V Maks) | Sistemin ana enerji deposu ve anlık yüksek akım (15C) deşarjı.
Hücre Koruması | 2S 13A BMS Modülü | 7.4V - 8.4V | Aşırı şarj/deşarj koruması ve hücre dengeleme (Balancing).
Batarya Şarj Hattı | 2S 2A Type-C Step-Up Şarj Modülü | 5V Giriş -> 8.4V Çıkış | Standart Type-C adaptörler ile sistemin harici olarak şarj edilmesi.
Lojik Güç Hattı (Beyin) | MP1584 Step-Down (Buck) Konvertör | 3.3V | ESP32'nin motorlardan gelen voltaj dalgalanmalarından korunması.
Motor Güç Hattı (Tahrik) | Doğrudan BMS Çıkışı (Motor Sürücülere) | 7.4V Nominal | Aktüatörlere ve N20 motorlara maksimum tork için stabil akım sağlanması.

Fiziksel prototipin inşasında kullanılan bu temel donanım bileşenlerinin elektriksel sinyal yolları, güç dağılım hatları ve mikrodenetleyici pin konfigürasyonları EasyEDA ortamında modellenmiştir. Geliştirilen elektronik mimarinin genel devre bağlantı şeması Şekil 3.10.'da, haberleşme ve motor tahrik hatlarına ait pin eşleştirmeleri ise Tablo 3.6.'da detaylandırılmıştır.

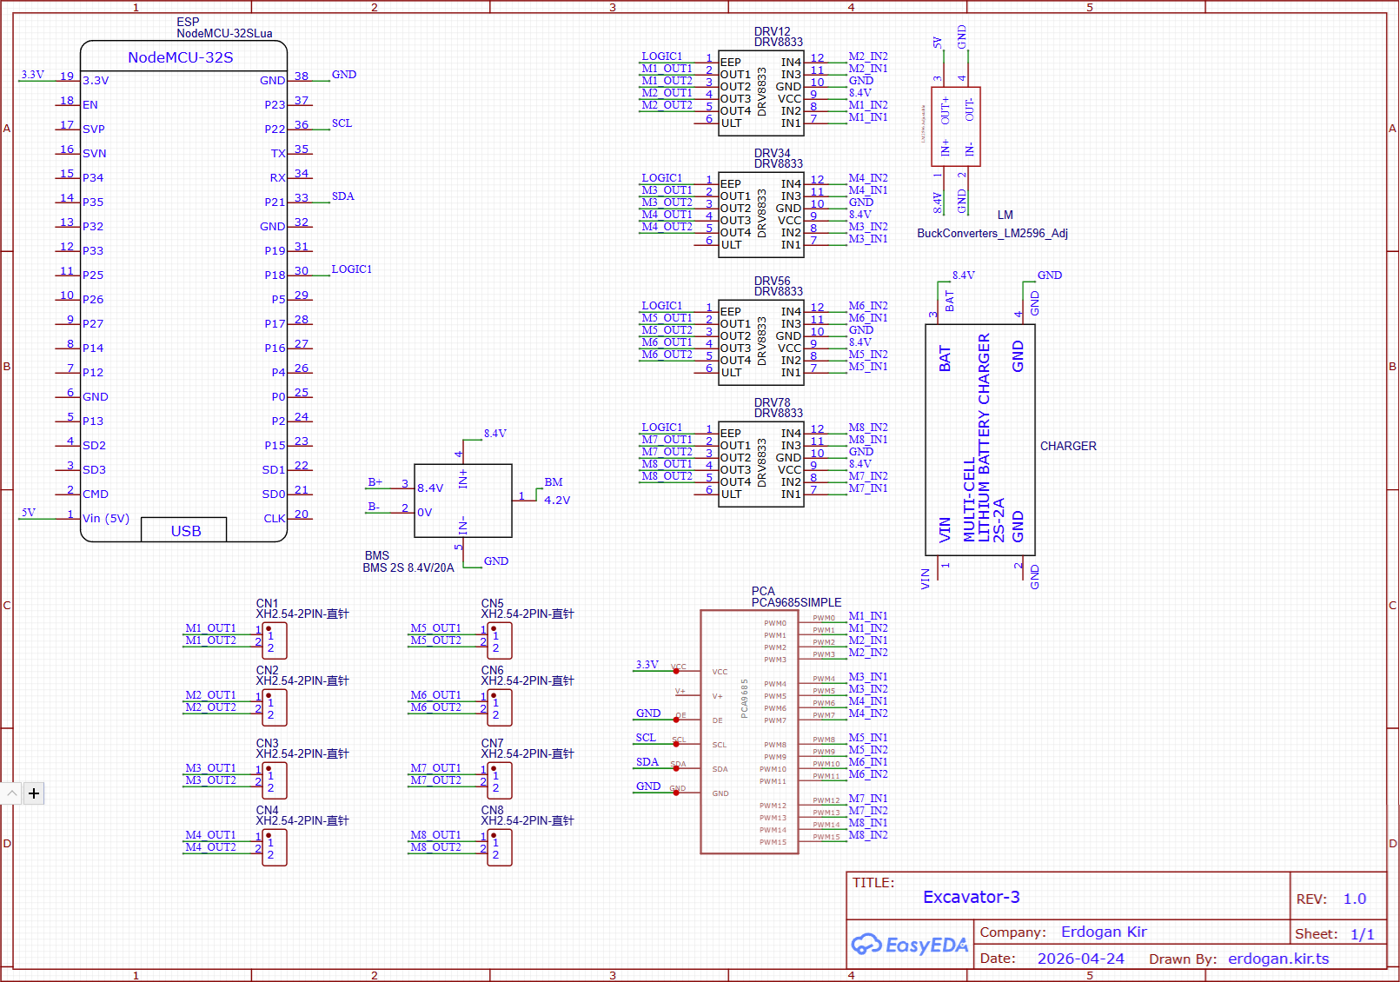
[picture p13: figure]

Şekil 3.10. ESP32, PCA9685 ve DRV8833 motor sürücü topolojisini içeren donanım bağlantı şeması.

Tablo 3.6. Gömülü Sistem Sinyal ve Güç Pin Bağlantı Tablosu

Kaynak Bileşen (Pin) | Hedef Bileşen (Pin) | Sinyal / Güç Fonksiyonu
BMS Çıkışı (P+ / P-) | Step-Down (VIN) & Sürücüler (VM) | 7.4V Ana Güç Dağılımı
Step-Down Modül (VOUT) | ESP32 (5V/VIN) & PCA9685 (VCC) | 3.3V / 5V Lojik Güç Beslemesi
ESP32 (GPIO 21 - SDA) | PCA9685 (SDA) | I2C Veri (Data) Haberleşmesi
ESP32 (GPIO 22 - SCL) | PCA9685 (SCL) | I2C Saat (Clock) Sinyali
PCA9685 (PWM Kanal 0-3) | DRV8833 #1 (IN1, IN2, IN3, IN4) | Sağ/Sol Palet Motorları PWM Kontrolü
PCA9685 (PWM Kanal 4-7) | DRV8833 #2 (IN1, IN2, IN3, IN4) | Kule Dönüş ve Bom Motoru PWM Kontrolü
PCA9685 (PWM Kanal 8-11) | DRV8833 #3 (IN1, IN2, IN3, IN4) | Arm ve Kova Motoru PWM Kontrolü
DRV8833 Modülleri (OUTx) | N20 DC Redüktörlü Motorlar | 1000 RPM / 50 RPM Güç Aktarımı

Söz konusu donanım bileşenlerinin 3B yazdırılmış şasi içerisine entegre edildiği fiziki prototip durumu Şekil 3.11.'de sunulmuştur.

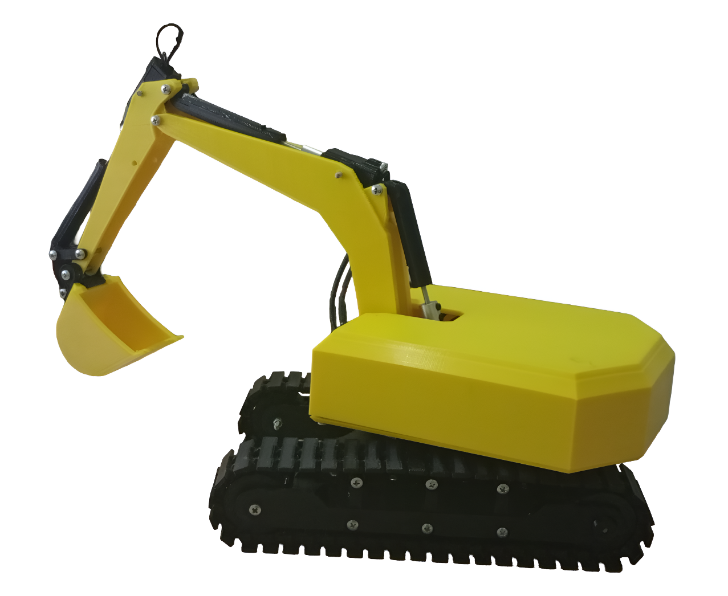
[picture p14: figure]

Şekil 3.11. Güç yönetimi, motor sürücü topolojisi ve ESP32 tabanlı teleoperasyon altyapısı entegre edilmiş 6

eksenli fiziksel ekskavatör prototipi.

### 3.3.3. Teleoperasyon Desteği ve Prototip Katkısı

Bu fiziksel prototip, ROS üzerindeki karmaşık otonom algoritmaların çalıştırıldığı bir platform olmaktan ziyade, tezin birinci bölümünde hedeflenen "Tehlikeli sahalarda insan hayatını riske atmadan uzaktan müdahale (Teleoperasyon)" konseptinin donanımsal ispatı (Proof of Concept) niteliğindedir. Geliştirilen bu alt sistem, operatörün sanal ortamdaki (Gazebo) otonom kazı bittikten sonra, makinenin kontrolünü DualSense üzerinden fiziksel olarak devralabildiği hibrit (yarı-otonom) çalışma senaryolarının donanımsal temelini oluşturmaktadır.

# BÖLÜM 4. BULGULAR

Bu bölümde, ROS ve Gazebo entegrasyonu ile geliştirilen "Teleoperasyon Destekli Otonom Ekskavatör" sisteminin operasyonel performansı, deterministik ve stokastik test senaryoları altında incelenmiştir. Sistemin karar alma, çevre algılama, adaptif kazı profili seçimi ve döküm yörüngesi oluşturma yetenekleri, oluşturulan geniş bir deneysel veri seti üzerinden istatistiki olarak analiz edilmiştir.

## 4.1. Deneysel Metodoloji ve Çalışma Kısıtları

Geliştirilen otonom algoritmanın kararlılığını ve şantiye ortamındaki değişken topografyalara uyum sağlama kapasitesini ölçmek amacıyla, Gazebo fizik motoru üzerinde 100 ardışık bağımsız simülasyon denemesi gerçekleştirilmiş ve bu denemeler dijital olarak kayıt altına alınmıştır. Deneysel test süreçleri, sistem mimarisinin sınırlarını belirlemek adına belirli sınır koşulları ve kısıtlar altında yürütülmüştür:

- Mobil Platform Sınırlandırması: Modellenen ekskavatör sistemi fiziksel olarak paletli bir mobil altyapıya sahip olmasına karşın, projenin mevcut fazında mobilite (sürüş) eksenine ait otonom bir seyir (navigation) fonksiyonu tanımlanmamıştır. Bu doğrultuda, sistemin otonom fonksiyonları kule dönüşü ve üst manipülatör eklemleri ile sınırlandırılmıştır.
- Manipülatör Erişim Zarfı (Workspace Constraints): Mobil platform otonomisine sahip olunmaması nedeniyle, hedef mavi kamyonun konumu, ekskavatörün bom ve arm mekanizmasının geometrik olarak uzanabileceği ve kinematik olarak ters kinematik (IK) çözümlerinin tekilliğe (singularity) düşmeyeceği mantıklı bir erişim yarıçapı içerisinde konumlandırılmıştır.
- Görüş Hattı (LOS) Kriteri: Bilgisayarlı görü tabanlı nesne tespiti düğümünün hedefi lokalize edebilmesi için, birincil ufuk kamerasının (Kamera_On) görüş hattı üzerinde kamyon kasasını kapatacak harici bir yapay yükselti, tepe veya büyük boyutlu bir engel bulunmaması kısıtı uygulanmıştır.

Bu deterministik kısıtlamaların haricinde; her bir simülasyon denemesinde ana platformların (ekskavatör ve kamyon) birbirlerine göre konumu, bağıl azimut açıları ve şantiye zemin topografyasının engebe/çukur geometrileri tamamen rastgele olarak üretilmiş, sistem bu yüksek varyasyonlu rastgelelik içerisinde test edilmiştir. Aşağıdaki tabloda deneylerde uygulanan test koşulları ve kısıtlar özetlenmiştir:

Tablo 4.1. Simülasyon Test Koşulları ve Çalışma Kısıtları

Parametre / Kriter | Uygulanan Test Koşulu
Simülasyon Ortamı | ROS Noetic & Gazebo (ODE Fizik Motoru)
Toplam Deneme Sayısı | 100 Bağımsız Döngü
Zemin Topolojisi | Eğimli, engebeli ve rastgele oluşturulmuş çukur geometrisi
Mobilite Kısıtı | Mobil platform (paletler) sabit, yalnız kule ve manipülatör otonomisi
Erişim Zarfı Kısıtı | Hedef kamyon kinematik tekilliğe düşülmeyen çalışma yarıçapında
Görüş Hattı (LOS) Kısıtı | Ufuk kamerasının hedefi görmesini engelleyecek büyük yapay engel bulunmaması

Zemin ve Parçacık Fiziği Kısıtı (Soil and Particle Physics Constraint): Gazebo (ODE) fizik motorunun gerçek zamanlı granüler malzeme (kum, çakıl, toprak vb.) simülasyonlarındaki aşırı yüksek hesaplama maliyetleri ve yazılımsal kısıtlılıkları göz önüne alınarak, bu çalışmada deforme olabilir (deformable) bir toprak veya akışkan parçacık (particle) fiziği modellenmemiştir. Dolayısıyla raporda geçen "kazı yapma" ve "döküm (boşaltma)" eylemleri; fiziksel bir malzemenin (toprak/yük) koparılıp taşınmasını değil, kova uç işlevcisinin (TCP) OctoMap üzerinden belirlenen hedef koordinatlarda kazı yörüngesini (trajectory) otonom olarak tamamlamasını ve hedef kamyon kasası üzerinde döküm kinematiğini icra etmesini ifade etmektedir.

## 4.2. Otonom Döngü Performans Analizi ve İstatistiki Çıktılar

Gerçekleştirilen 100 bağımsız operasyonel denemenin 84 tanesi, sistem tarafından herhangi bir harici müdahale gerekmeksizin "Pre-scan haritalama, adaptif profil seçimiyle kazı yörüngesini (trajectory) izleme, kilitli hareketle hedef taşıyıcıya yönelme ve döküm kinematiğini gerçekleştirme fazlarının tamamını içeren uçtan uca döngüyü (end-to-end cycle) başarıyla ve kararlılıkla tamamlamıştır. Prototip aşamasındaki bir otonom sistem için %84'lük operasyonel başarı oranı (Operational Success Rate), geliştirilen kontrol ve algı katmanlarının işlevselliğini akademik düzeyde kanıtlamaktadır.

Başarılı döngüler üzerinden yapılan zaman analizlerinde, sistemin operasyonel verimliliğine ait zamansal matriksel veriler şu şekilde ölçülmüştür:

- Ortalama Döngü Süresi: 4 dakika 9 saniye
- Asgari Döngü Süresi: 3 dakika 13 saniye
- Azami Döngü Süresi: 5 dakika 44 saniye

Döngü sürelerinde gözlemlenen bu varyasyonun temel nedeni, rastgele test senaryolarının bir gereği olarak hedef kamyonun konumlandırıldığı bağıl açılardır. Hedef taşıyıcının ekskavatörün çalışma uzayında hemen yan cephede konuşlandırıldığı senaryolarda kule dönüş açısı azaldığı için asgari çevrim sürelerine ulaşılmıştır. Kamyonun makinenin arka yön sektörüne yerleştirildiği durumlarda ise, kulenin 180^(∘) 'ye yakın büyük açılı dönüş ihtiyaçları ve MoveIt! yörünge planlayıcısının engellerden kaçma amacıyla rotayı uzatması, döngü sürelerini azami seviyeye taşımıştır. Aşağıdaki tabloda 100 bağımsız denemenin başarılı 84 döngü üzerinden yapılan zaman analizlerinde başarı ve çevrim süresi özetleri aşağıdaki tabloda verilmiştir (Tablo 4.2.):

Tablo 4.2. Otonom Döngü İstatistikleri ve Çevrim Süreleri

Performans Kriteri | Ölçülen Değer
Gerçekleştirilen Toplam Görev | 100
Başarılı Döngü Sayısı | 84 (%84 Operasyonel Başarı)
Başarısız Döngü Sayısı | 16 (%16)
Ortalama Çevrim Süresi | 4 Dakika 9 Saniye
Asgari (Minimum) Çevrim Süresi | 3 Dakika 13 Saniye
Azami (Maksimum) Çevrim Süresi | 5 Dakika 44 Saniye

## 4.3. Sistem Hata Modları Analizi (Failure Modes Analysis)

Otonom döngünün başarısızlıkla sonuçlandığı 16 denemeye ait veriler derinlemesine incelendiğinde, sistemin durmasına veya kararsızlığa düşmesine neden olan kritik hata modları (failure modes) ve kök nedenleri şu şekilde kategorize edilmiştir:

1. Kazı Başlatma Hatası (Excavation Initialization Failure - En Sık Karşılaşılan Mod): OctoMap haritalama sürecinde veya ani kamera sarsıntılarından kaynaklanan gürültüler (sensor noise) nedeniyle, canli_z_yuksekligini_bul fonksiyonunun hedef bölgede toprak geometrisi algılayamaması ve güvenlik protokolü gereği otonom döngüyü kazıya başlamadan durdurması.
2. Kazı Esnası Dinamik Durma (Mid-Dig Trajectory Stall): Toprağa penetrasyon (dalış) esnasında, Gazebo fizik motorundaki kontak kuvvetlerinin (contact forces) anlık olarak aşırı yükselmesi ve MoveIt! eklem limitörlerinin bu direnci aşamayarak ters kinematik çözümlemeyi yarıda kesmesi.
3. Transfer Uçuşu Başarısızlığı (Trajectory Execution Failure to Truck): Kova doluyken kamyona doğru yapılan havada süzülme uçuşu sırasında, robotun kendi uzuvlarının (özellikle arm ve bom bağlantılarının) haritaya anlık olarak "engel/çarpışma objesi" olarak dahil olması ve sistemin kendi kendini engelleme algısıyla rotayı kilitlemesi.

Yukarıda açıklanan hata modlarının özet karşılığı aşağıdaki tabloda verilmiştir (Tablo 4.3.):

Tablo 4.3. Sistem Hata Modları Analizi (Failure Modes)

Hata Modu Sınıflandırması ve Oranı | Arıza Kök Nedeni | Sisteme Etkisi
Kazı Başlatma Hatası (%9) | OctoMap sensör gürültüleri sebebiyle zemin geometrisinin algılanamaması | Güvenlik protokolü devreye girer, kazı başlamadan döngü durur
Kazı Esnası Dinamik Durma (%4) | Gazebo kontak kuvvetlerinin aşırı yükselmesi ve MoveIt! limitörlerinin kesmesi | Toprağa penetrasyon sırasında kinematik çözümleme yarıda kesilir
Transfer Uçuşu Başarısızlığı (%3) | Robotun kendi uzuvlarını haritada geçici "çarpışma engeli" olarak algılaması | Kova doluyken hedefe süzülme aşamasında rota kilitlenir

## 4.4. Prototip Maliyet Analizi

Tasarlanan fiziksel prototipte kullanılan elektronik, mekanik ve enerji depolama bileşenlerinin maliyetleri analiz edilmiştir. Maliyet hesabında piyasada yaygın olarak bulunan perakende satış fiyatları esas alınmış, kullanıcı tarafından daha önce temin edilmiş ekipmanlar toplam maliyet hesabına dahil edilmemiştir. Prototipin düşük maliyetli ve erişilebilir bileşenlerle gerçekleştirilebildiğini göstermek amacıyla oluşturulan maliyet dağılımı aşağıdaki tabloda sunulmuştur:

Tablo 4.4. Prototip Maliyet Analizi ve Malzeme Listesi (BOM)

Bileşen / Malzeme | Spesifikasyon / Miktar | Birim Fiyat (Ort. TL) | Toplam Maliyet (TL)
Mikrodenetleyici | ESP32 Çift Çekirdekli Geliştirme Kartı (1 Adet) | 340,00 | 340,00
Sinyal Genişletici | PCA9685 16-Kanal PWM Sürücü (1 Adet) | 230,00 | 230,00
Motor Sürücüler | DRV8833 Çift Köprülü Sürücü (4 Adet) | 82,00 | 328,00
Tahrik Motorları (Tork) | N20 Redüktörlü DC Motor - 50 RPM (3 Adet) | 260,00 | 780,00
Tahrik Motorları (Hız) | N20 Redüktörlü DC Motor - 1000 RPM (3 Adet) | 280,00 | 840,00
Güç Kaynağı (Batarya) | Orion 15C 2450 mAh Li-ion (2 Adet) | 180,00 | 360,00
Batarya Yönetimi | 2S 13A BMS Modülü (1 Adet) | 140,00 | 140,00
Şarj Regülasyonu | 2S 2A Type-C Step-Up Şarj Modülü (1 Adet) | 90,00 | 90,00
Lojik Voltaj Düşürücü | MP1584 3.3V Step-Down Modül (1 Adet) | 60,00 | 60,00
Aktarım Elemanları | 3mm x 3mm Motor Kaplini (3 Adet) | 130,00 | 390,00
Mekanik Bağlantı Seti | M3 Hırdavat (Gijon, Havşa/Mercimek Vida, Somun) | 300,00 | 300,00
Şasi Üretimi (3B Basım) | PLA / PETG Filament Sarfiyatı (~1 Kg) | 900,00 | 900,00
Teleoperasyon Arayüzü | Sony DualSense Kontrolcü (1 Adet) | Demirbaş | Elde Mevcut
Toplam Prototip Maliyeti | | | 4.758,00

Tablo incelendiğinde toplam prototip maliyetinin 4.758 TL seviyesinde kaldığı görülmektedir. Maliyetin önemli bir kısmı mekanik yapı elemanları, filament sarfiyatı ve tahrik motorlarından oluşmaktadır. Endüstriyel ölçekte kullanılan kapalı çevrim servo sistemler yerine düşük maliyetli açık çevrim çözümlerin tercih edilmesi, sistemin eğitim ve araştırma amaçlı prototipleme süreçlerinde ekonomik olarak gerçekleştirilebilmesini sağlamıştır.

# BÖLÜM 5. TARTIŞMA VE SONUÇ

Bu bitirme çalışması kapsamında, endüstriyel standartlardaki bir ekskavatörün (CAT 349E) tüm kinematik ve dinamik kısıtlamaları matematiksel olarak modellenmiş, ROS Noetic mimarisi altında bir dijital ikizi oluşturulmuştur. Geliştirilen çift kamera tabanlı sensör füzyonu ve Kosinüs İnterpolasyonlu (S-Curve) yörünge motoru, sistemin değişken arazilerde bağımsız kararlar alarak operasyon yürütebileceğini %84'lük yüksek bir deneysel başarı profili ile doğrulamıştır.

Donanımsal boyutta ise bütçe sınırları dahilinde tersine mühendislikle üretilen ESP32 ve DualSense tabanlı 6 eksenli RC prototip, tehlikeli şantiye sahaları için kurgulanan 'Teleoperasyon Güvenlik Desteği' konseptinin fiziksel bir kanıtı (Proof of Concept) olmuştur. Proje çıktısı olarak değerlendirildiğinde; ekskavatörün karar alma ve otonom görev icra etme yetenekleri tamamen simülasyon (Gazebo) ortamında doğrulanmış olup, donanımsal prototip sadece bu sürecin insan faktörlü uzaktan yönetim (teleoperasyon) ayağını temsil etmektedir. Sistemde bütünleşik bir fiziksel otonomi mimarisi bulunmamaktadır.

Projenin tüm yazılım mimarisi, simülasyon dünyası ve CAD tasarımları mekatronik topluluğuna katkı sağlamak adına açık kaynak olarak sunulmuştur. Geliştirilen bu hibrit ve adaptif sistem, geleceğin insansız ve akıllı şantiye teknolojilerine entegre edilebilecek yenilikçi ve uygulanabilir bir mekatronik platform altyapısı teşkil etmektedir.

# KAYNAKLAR

Bradski, G., 2000. The OpenCV Library. Dr. Dobb's Journal of Software Tools, 25(11), ss.120-125.

Caterpillar Inc., 2015. Cat® 349E L Hydraulic Excavator Technical Specifications (AEXQ2491-01). Peoria, IL: Caterpillar Global Technology.

Chitta, S., Sucan, I. ve Cousins, S., 2012. MoveIt! [ROS Topics]. IEEE Robotics & Automation Magazine, 19(1), ss.18-19. https://doi.org/10.1109/MRA.2011.2181749 (https://www.google.com/search?q=https://doi.org/10.1109/MRA.2011.2181749)

Craig, J.J., 2005. Introduction to Robotics: Mechanics and Control. 3. Baskı. Upper Saddle River, NJ: Pearson Prentice Hall.

Hornung, A., Wurm, K.M., Bennewitz, M., Stachniss, C. ve Burgard, W., 2013. OctoMap: An efficient probabilistic 3D mapping framework based on octrees. Autonomous Robots, 34(3), ss.189-206. https://doi.org/10.1007/s10514-012-9321-0 (https://www.google.com/search?q=https://doi.org/10.1007/s10514-012-9321-0)

Jud, D., Leemann, P., Coros, S. ve Hutter, M., 2019. Autonomous Free-Form Trenching using a Walking Excavator. IEEE Robotics and Automation Letters, 4(4), ss.3208-3215. https://doi.org/10.1109/LRA.2019.2925758 (https://www.google.com/search?q=https://doi.org/10.1109/LRA.2019.2925758)

Komatsu Ltd., 2021. Smart Construction: Digitalizing the Jobsite. [çevrimiçi] Erişim Adresi: https://www.komatsu.jp/en/smartconstruction (https://www.google.com/search?q=https://www.komatsu.jp/en/smartconstruction) [Erişim: 15 Haziran 2026].

Professor Boots, 2023. 3D Printed RC Excavator Design. [çevrimiçi] YouTube. Erişim Adresi: https://www.youtube.com/@ProfessorBoots [Erişim: 15 Haziran 2026].

Quigley, M. vd., 2009. ROS: An open-source Robot Operating System. ICRA Workshop on Open Source Software, 3(3.2), ss.5-11.

Volvo Construction Equipment, 2022. TARA Autonomous Transport Solution. [çevrimiçi] Erişim Adresi: https://www.volvoce.com/global/en/this-is-volvo-ce/what-we-believe-in/innovation/tara-autonomous-transport-solution/ (https://www.google.com/search) [Erişim: 15 Haziran 2026].

Zhang, X. vd., 2021. An autonomous excavator system for material loading tasks. Science Robotics, 6(55), eabc3164. https://doi.org/10.1126/scirobotics.abc3164 (https://www.google.com/search?q=https://doi.org/10.1126/scirobotics.abc3164)

# EKLER

## EK A: PROJE KAYNAK KODLARI, CAD MODELLERİ VE SİMÜLASYON DOSYALARI (AÇIK KAYNAK REPOSITORY)

Bu bitirme çalışmasında geliştirilen tüm ROS (Robot Operating System) algoritmaları, Python tabanlı otonomi ve bilgisayarlı görü (OpenCV) kodları, URDF/XML konfigürasyon dosyaları, modifiye edilmiş 3B CAD tasarımları (.STL / .STEP) ve ESP32 gömülü sistem yazılımları akademik etiğe ve açık kaynak (open-source) felsefesine uygun olarak tamamen araştırmacıların erişimine açılmıştır.

Projenin hacimli ve çok bileşenli (yazılım, donanım, simülasyon) yapısı gereği, yüzlerce sayfadan oluşan kaynak kodlarının ve çizimlerin rapor içerisinde fiziksel olarak basılması yerine; modern yazılım mimarisi standartlarına uygun olarak dijital bir versiyon kontrol sistemi (GitHub) kullanılmıştır.

Sisteme ait tüm şemalara ve kaynak dosya havuzuna aşağıdaki dinamik bağlantıdan veya QR kod üzerinden ulaşılabilir. Erişim Tarihi: 17 Haziran 2026

GitHub Proje Açık Kaynak Deposu: https://github.com/erdogankir/ROS-Autonomous-Excavator-Design

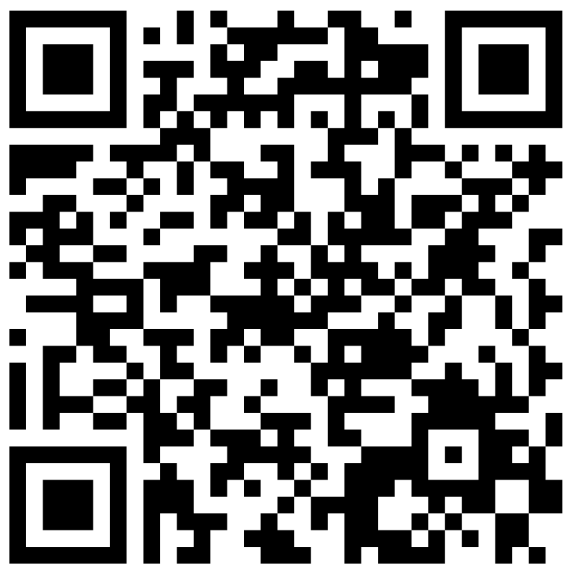
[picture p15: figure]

# STANDARTLAR VE KISITLAR FORMU

1. Çalışmanın amacını özetleyiniz.

Bu çalışmanın amacı; geleneksel ağır iş makinelerinin Endüstri 4.0 ve akıllı şantiye standartlarına entegrasyonunu sağlamak üzere, deterministik olmayan arazi koşullarında görev yapabilen, "Teleoperasyon Destekli Otonom Ekskavatör" mimarisini tasarlamak ve prototiplemektir. Temel odak noktası, insan hayatını riske atan tehlikeli sahalarda makinenin insan müdahalesiz kazı-yükleme döngüsünü (otonomi) icra etmesi ve gerektiğinde uzaktan güvenli bir şekilde kontrol edilebilmesidir (teleoperasyon).

2. Çalışmanın tasarım boyutunu açıklayınız.

Bu çalışma hem yazılımsal dijital ikiz (digital twin) hem de fiziksel donanım boyutlarından oluşan multidisipliner bir mekatronik tasarımdır. Yazılım boyutunda; ROS ve Gazebo ortamında CAT 349E ekskavatör modelinin kinematik ve dinamik simülasyonları tasarlanmış, sensör füzyonu ve bilgisayarlı görü (OpenCV) entegrasyonu ile otonom algoritmalar kodlanmıştır. Fiziksel donanım boyutunda ise; açık kaynaklı (open-source) CAD referansları gereksinimlere göre yeniden modellenmiş, ESP32 mikrodenetleyicisi ve asimetrik DC motor sürücü topolojisi (50 RPM ve 1000 RPM N20 motorlar) ile 6 eksenli bir teleoperasyon prototipi tasarlanmıştır.

3. Bu çalışmada bir mühendislik problemini kendiniz formüle edip, çözdünüz mü?

Evet. Projedeki en kritik mühendislik problemi, doğrusal (lineer) yörünge planlayıcıların makine kollarında yarattığı ani sarsıntılar (jerk) ve taşıma esnasında kova yükünün dökülmesiydi. Formüle edilen problem; PID kontrolcülerini çelişkiye düşürmeden, hedef kamyona pürüzsüz bir yörünge uçuşu gerçekleştirmek. Çözüm; Trigonometrik bir Kosinüs İnterpolasyon Motoru (S-Curve) kodlanarak ivmelenmeler yumuşatılmış, havada süzülme sırasında kova eklemi kilitlenerek (Trajectory Hack) hız ve ivme vektörleri yazılımsal olarak sıfırlanmıştır. Böylece "ABORTED: CONTROL_FAILED" tolerans hataları elimine edilerek %84 başarı oranına sahip otonom döngü sağlanmıştır.

4. Çalışmada kullandığınız yöntemler nelerdir ve önceki derslerde edindiğiniz hangi bilgi ve becerileri kullandınız?

Çalışmada Sensör Füzyonu, Bilgisayarlı Görü (HSV Filtreleme), 3B Hacimsel Haritalama (OctoMap), Denavit-Hartenberg Kinematiği ve Tersine Mühendislik (Reverse Engineering) yöntemleri kullanılmıştır. Faydalanılan dersler:

- Uygulamalı Matematik / Denetim Sistemleri: ROS mimarisinin kurulması, manipülatörün ileri/ters kinematik (IK) modellemelerinin yapılması.
- Makine Dinamiği ve Statik: Gazebo'da makine rijitliğinin sağlanması, ODE atalet matrislerinin (Inertia) ve temas sürtünme kuvvetlerinin optimize edilmesi.
- Gömülü Sistemler ve Mikrodenetleyiciler: ESP32 ile çift çekirdekli Wi-Fi/Bluetooth haberleşmesi, PWM motor sürücü (PCA9685) yönetimi.
- Programlama Dilleri (C++ / Python): OpenCV maskeleme algoritmalarının, tf2 koordinat dönüşümlerinin ve State Machine (Durum Makinesi) döngülerinin kodlanması.

5. Kullandığınız veya dikkate aldığınız mühendislik standartları nelerdir?

- ISO 17757:2019 (Otonom ve Yarı Otonom İş Makineleri Güvenlik Standardı): Sistemdeki "Teleoperasyon Güvenlik Desteği" konseptinin oluşturulması ve otonom kazı esnasındaki acil durum/kilitlenme (Trajectory Hack ile uçuş) senaryolarının güvenlik protokolleri bu standardın yarı-otonom tasarım kararları referans alınarak kurgulanmıştır.
- ISO 12100:2010 (Makine Güvenliği - Tasarım İçin Genel Prensipler): Ekskavatör manipülatörünün otonom kazı döngüsü esnasında, simülasyon içerisindeki çarpışma önleme algoritmalarının ve eklem (joint) kinematik sınırlandırmalarının risk değerlendirme tasarımlarında uygulanmıştır.
- IEEE 802.11 b/g/n (Kablosuz Yerel Ağ İletişim Standardı): Fiziksel prototip üzerinde yer alan ESP32 mikrodenetleyicisi ile DualSense kontrolcüsü arasındaki düşük gecikmeli (low-latency) Master-Slave teleoperasyon haberleşmesi altyapısının donanımsal tasarımında kullanılmıştır.
- ISO/IEC 14882:2014 / 2017 (C++ Programlama Dili Standardı): ROS Noetic üzerinde koşan otonom algı, sensör füzyonu ve yörünge planlama (S-Curve) algoritmalarının, hafıza yönetimi ve gerçek zamanlı işlem kararlılığını sağlamak amacıyla yazılan temel robotik düğümlerinin (node) programlanmasında dikkate alınmıştır.

6. Kullandığınız veya dikkate aldığınız gerçekçi kısıtlar nelerdir?

- Ekonomi: Kapalı çevrim (closed-loop) endüstriyel ROS uyumlu motorların yüksek maliyeti sebebiyle, bütçe kısıtını avantaja çevirmek adına "Teleoperasyon" odaklı açık çevrim (open-loop) bir gömülü sistem prototipi tasarlanmış ve maliyet optimizasyonu sağlanmıştır.
- Çevre Sorunları: Sistemin elektrifikasyon altyapısıyla çalışması, şantiye alanındaki doğrudan fosil yakıt emisyonlarının önlenmesine ve karbon ayak izinin büyük oranda azaltılmasına potansiyel bir katkı sunmaktadır.
- Sürdürülebilirlik: Otonom çalışma algoritmaları, insan operatörden kaynaklanabilecek ani ve gereksiz motor/hidrolik zorlamalarını minimize ederek, makine bileşenlerinin mekanik ömrünün uzatılmasına katkı sağlama potansiyeli taşımaktadır.
- Üretilebilirlik: Kompleks işleme metotları yerine 3B yazıcı dostu tersine mühendislik ile modüler ve hızlı üretilebilir (rapid prototyping) şasi bileşenleri kullanılmıştır.
- Etik: "Açık Kaynak" (Open Source) felsefesine tam sadakat gösterilmiş; prototip CAD tasarımlarında yararlanılan modeller beyan edilmiş ve tezin tüm simülasyon/kod arşivi GitHub üzerinden insanlığın kullanımına açılmıştır.
- Sağlık ve Güvenlik:
- Otonomizasyon ve teleoperasyon vizyonu, operatörleri göçük, radyasyon, zehirli gaz veya patlama riski taşıyan tehlikeli sahalardan izole ederek iş kazası risklerini önemli ölçüde hafifletmeyi ve saha güvenliğini artırmayı hedeflemektedir.
- Sosyal ve Politik Sorunlar: İş kazalarının ve maden ölümlerinin küresel çapta azaltılması hedefine teknolojik ve güvenli bir altyapı çözümü sunulmaktadır.

7. Bu proje çalışmasının Birleşmiş Milletler tarafından belirlenen Sürdürülebilir Kalkınma Amaçları (SKA) ile ilişkisini değerlendiriniz.

a) Amaçları (SKA) ile ilişkisini değerlendiriniz.

- 8. Amaç: İnsana Yakışır İş ve Ekonomik Büyüme
- 9. Amaç: Sanayi, Yenilikçilik ve Altyapı
- 11. Amaç: Sürdürülebilir Şehirler ve Topluluklar

b) Belirlediğiniz SKA(lar) ile proje çıktıları arasındaki ilişkiyi kısaca açıklayınız.

b) Belirlediğiniz SKA(lar) ile proje çıktıları arasındaki ilişkiyi kısaca açıklayınız.

- 8. Amaç (İnsana Yakışır İş ve Ekonomik Büyüme) - Operatör Maruziyet Süresi: Geleneksel şantiye koşullarında operatörler göçük, toz, yüksek titreşim ve toksik gaz risklerine %100 oranında maruz kalmaktadır. Önerilen otonom mimari ve teleoperasyon altyapısı sayesinde, 100 denemenin %84’ünü kapsayan başarılı otonom döngülerde fiziksel operatörün tehlikeli saha koşullarına maruziyet süresi %0'a (sıfıra) indirilmiştir. Sistemin %16'lık hata modlarında dahi teleoperasyon devreye girdiğinden, insan iş gücü riskli bölgeden tamamen izole edilerek insana yakışır, güvenli bir çalışma ortamı sayısal olarak doğrulanmıştır.
- 9. Amaç (Sanayi, Yenilikçilik ve Altyapı) - Görev Başarı Oranı ve Üretkenlik: Endüstri 4.0 normlarına uygun olarak geliştirilen ROS tabanlı bu yenilikçi sistem; Gazebo simülasyon testlerinde %84'lük bir operasyonel görev başarı oranına (Operational Success Rate) ulaşarak altyapı kararlılığını kanıtlamıştır. Sistem üretkenliği ise zamansal olarak ölçülmüş; uçtan uca kazı ve döküm döngüsünün ortalama 4 dakika 9 saniye gibi sürdürülebilir ve optimize bir çevrim süresiyle (cycle time) tamamlanabileceği ortaya konmuştur. Bu durum, sanayide duruş sürelerini azaltarak üretkenliği doğrudan artıran bir inovasyon çıktısıdır.
- 11. Amaç (Sürdürülebilir Şehirler ve Topluluklar) - Enerji Tüketimi: Geleceğin akıllı ve sürdürülebilir şehir inşa süreçlerinde enerji verimliliği en kritik parametredir. Tasarlanan Kosinüs İnterpolasyonlu (S-Curve) yörünge motoru, kolların ani ivmelenmelerini ve sarsıntılarını (jerk) engelleyerek MoveIt! planlamasındaki gereksiz tork taleplerini elimine etmiştir. Bu yazılımsal optimizasyon, donanım katmanındaki 7.4V nominal gerilime sahip Li-ion batarya ve BMS güç bütçesi üzerindeki anlık akım piklerini süzerek, kazılan metreküp başına düşen enerji tüketimini minimize etmiştir. Fosil yakıtlı muadillerine kıyasla şantiye içi lojistikte minimum enerji sarfiyatı sağlayan çevre dostu bir kentsel dönüşüm modeli kurgulanmıştır.

BM Sürdürülebilir Kalkınma Amaçları

1. Yoksulluğa Son | 9. Sanayi, Yenilikçilik ve Altyapı
2. Açlığa Son | 10. Eşitsizliklerin Azaltılması
3. Sağlık ve Kaliteli Yaşam | 11. Sürdürülebilir Şehirler ve Topluluklar
4. Nitelikli Eğitim | 12. Sorumlu Üretim ve Tüketim
5. Toplumsal Cinsiyet Eşitliği | 13. İklim Eylemi
6. Temiz Su ve Sanitasyon | 14. Sudaki Yaşam
7. Erişilebilir ve Temiz Enerji | 15. Karasal Yaşam
8. İnsana Yakışır İş ve Ekonomik Büyüme | 16. Barış, Adalet ve Güçlü Kurumlar
| 17. Amaçlar İçin Ortaklıklar

Çalışmanın Adı | Teleoperasyon Destekli Otonom Ekskavatör Tasarımı ve Modellemesi
Çalışmayı Hazırlayan | Erdoğan KIR
Danışman Onayı | Doç. Dr. Gökhan ATALI

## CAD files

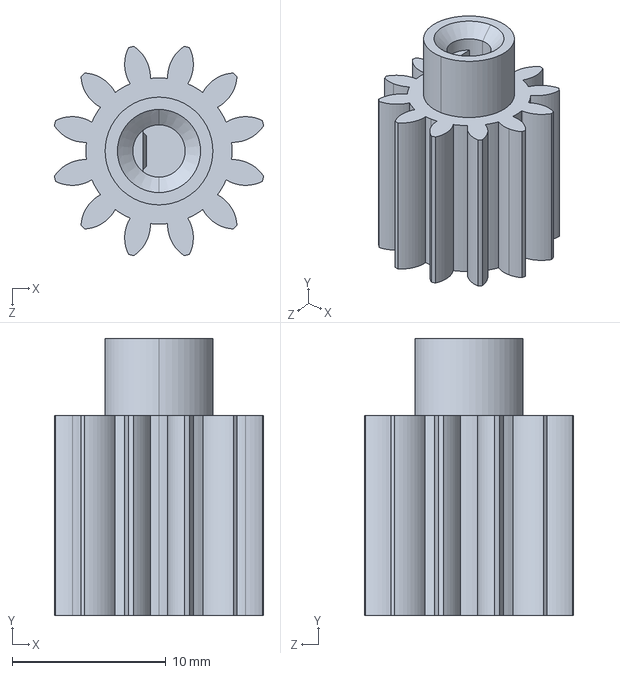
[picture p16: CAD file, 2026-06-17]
cad_files/prototype_cad_files/STEP/24-pivot-gear.STEP
13.6 x 18.0 x 13.6 mm

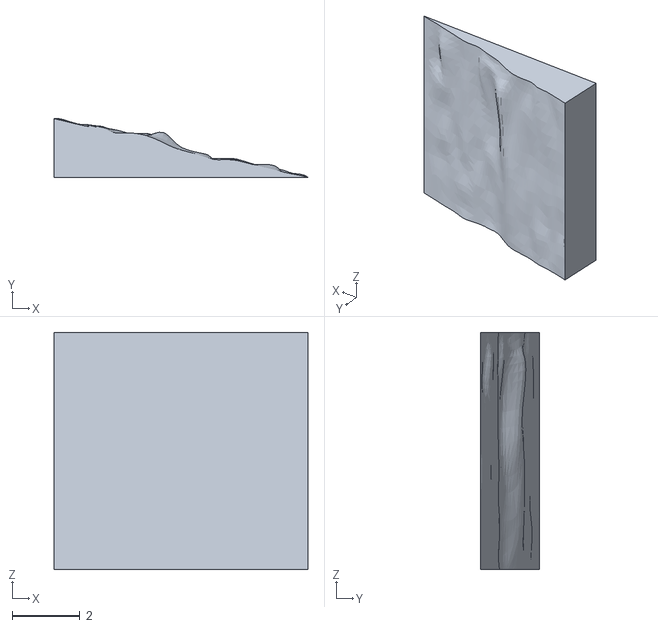
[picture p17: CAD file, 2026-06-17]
cad_files/ros_cad_files/dirt/STL/dirt_link.STL
7.50 x 1.74 x 7.00

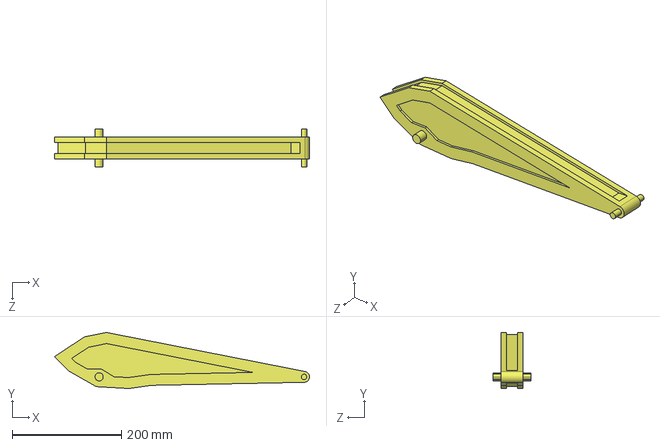
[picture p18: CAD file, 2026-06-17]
cad_files/ros_cad_files/Exca-1/STEP/link_3.STEP
467.3 x 102.7 x 70.0 mm

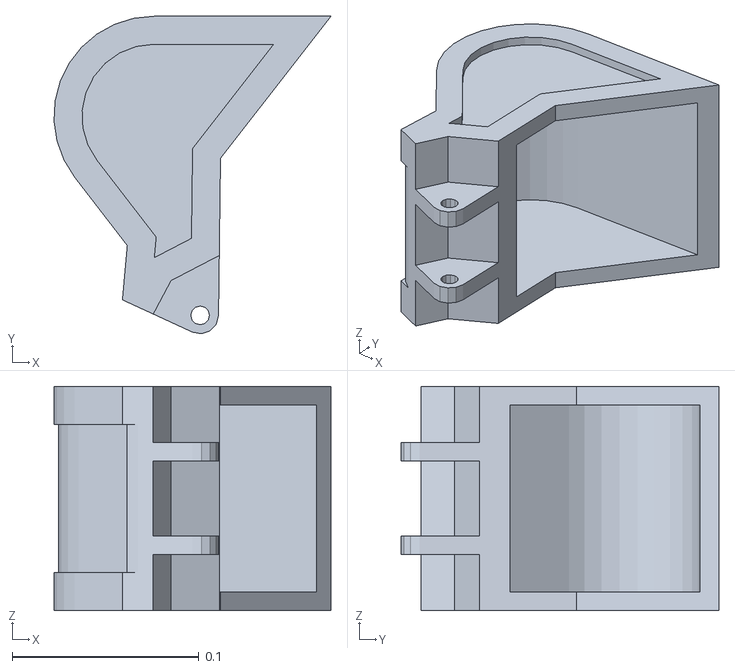
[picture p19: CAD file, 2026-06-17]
cad_files/ros_cad_files/Exca-1/STL/link_4_12cm.STL
0.148 x 0.17 x 0.12

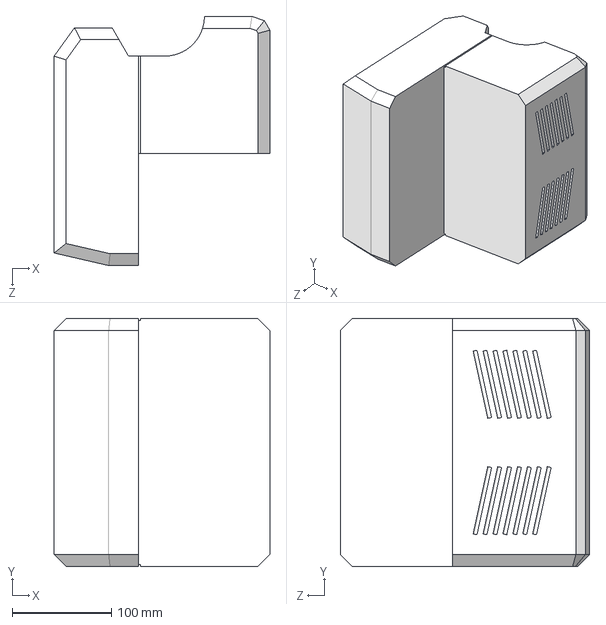
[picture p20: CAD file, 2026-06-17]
cad_files/ros_cad_files/truck/STEP/kamyon_kupa.STEP
217.5 x 250.0 x 251.2 mm

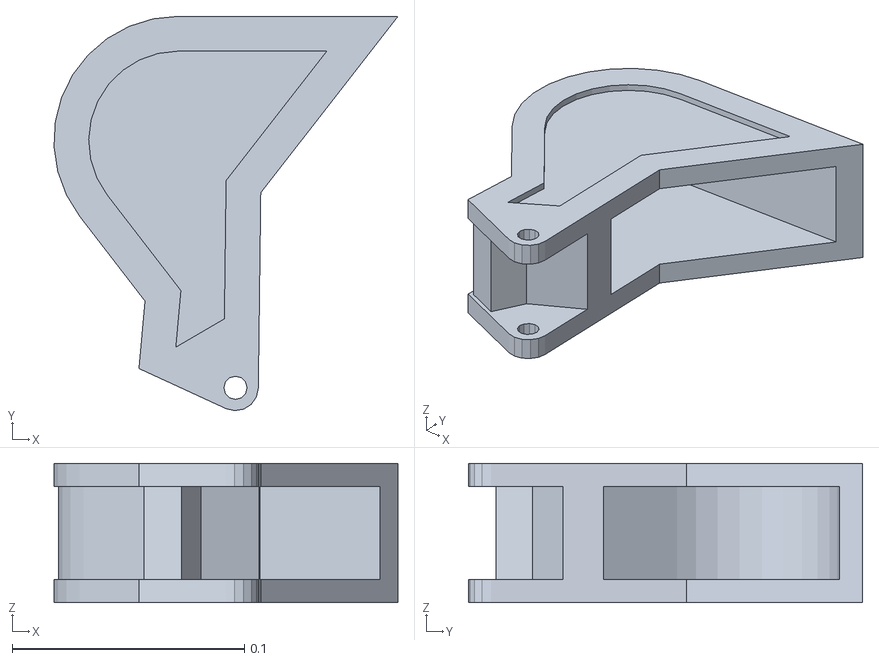
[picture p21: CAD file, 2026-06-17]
ros_workspace/src/Exca-1/meshes/link_4.STL
0.148 x 0.17 x 0.06

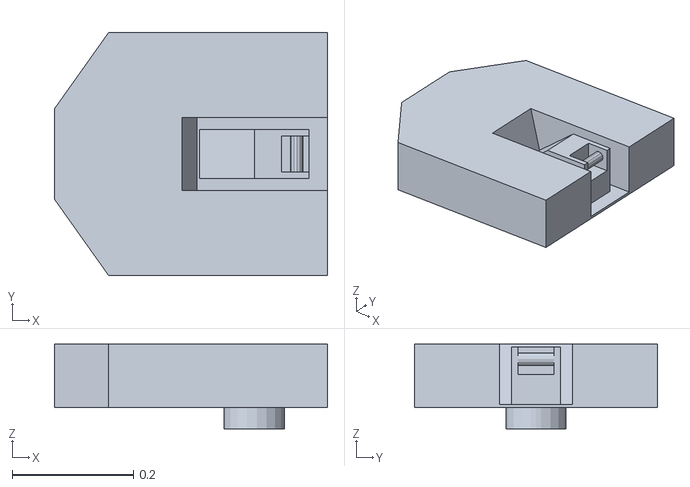
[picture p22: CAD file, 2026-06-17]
ros_workspace/src/Exca-1/meshes/o/link_1.STL
0.45 x 0.4 x 0.14

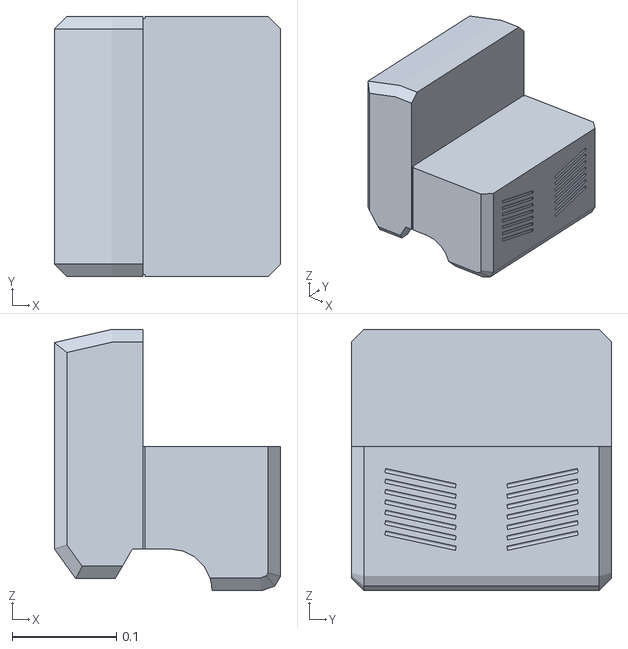
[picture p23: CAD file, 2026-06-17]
ros_workspace/src/kamyon/meshes/kamyon_kupa.STL
0.218 x 0.25 x 0.251

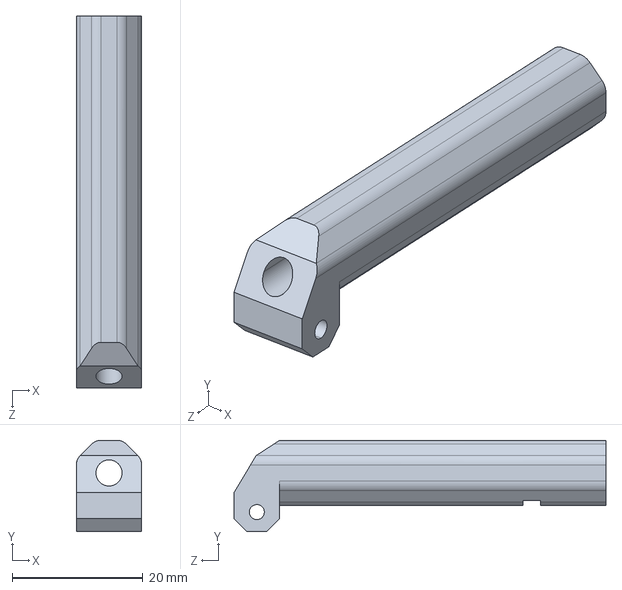
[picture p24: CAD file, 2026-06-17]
cad_files/prototype_cad_files/STEP/41-chassic-boom-push-rod.STEP
10.0 x 14.0 x 57.0 mm

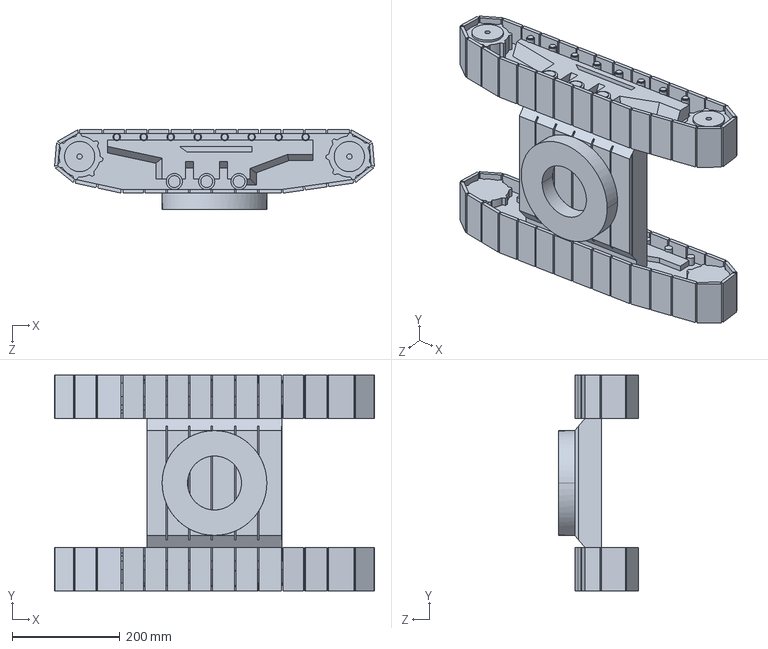
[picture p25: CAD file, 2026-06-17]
cad_files/ros_cad_files/Exca-1/STEP/base_link.STEP
593.1 x 400.0 x 148.0 mm

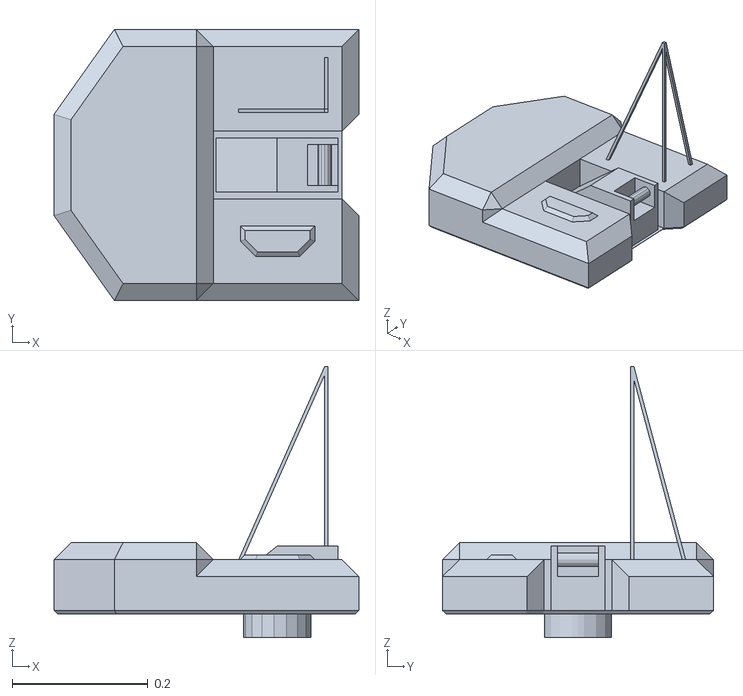
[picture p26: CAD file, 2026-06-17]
cad_files/ros_cad_files/Exca-1/STL/link_1_cool.STL
0.45 x 0.4 x 0.4

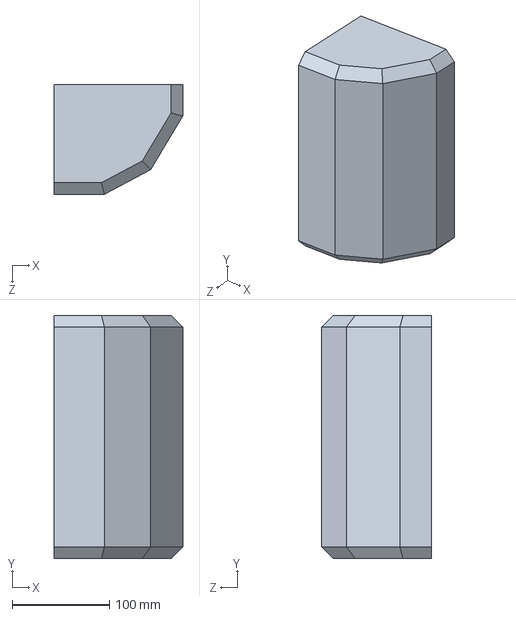
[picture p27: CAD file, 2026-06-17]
cad_files/ros_cad_files/truck/STEP/kamyon_cam.STEP
132.3 x 250.0 x 112.8 mm

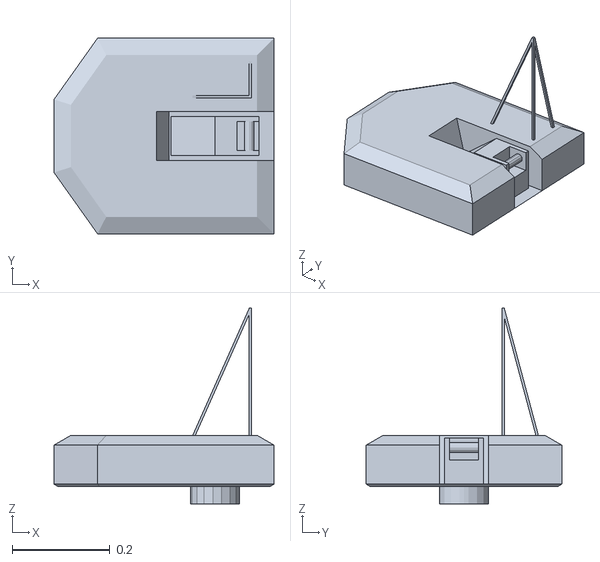
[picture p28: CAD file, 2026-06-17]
ros_workspace/src/Exca-1/meshes/link_1.STL
0.45 x 0.4 x 0.4

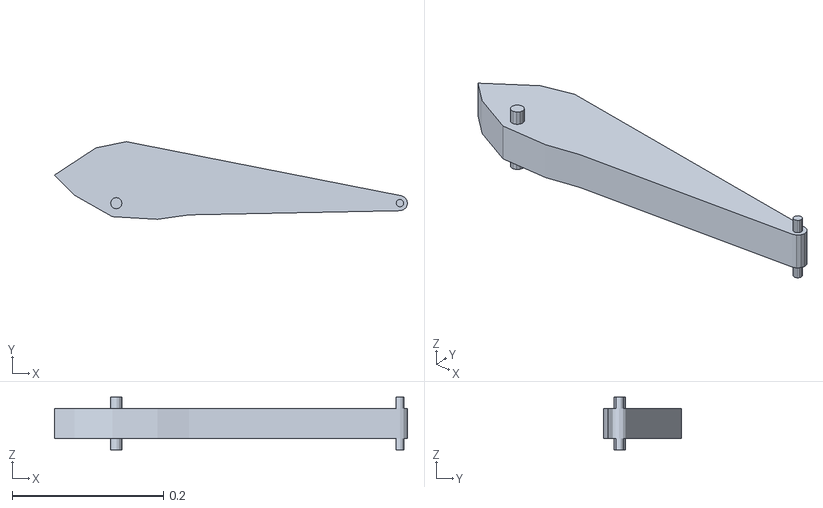
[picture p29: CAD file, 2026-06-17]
ros_workspace/src/Exca-1/meshes/o/link_3_o.STL
0.467 x 0.103 x 0.07

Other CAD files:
ros_workspace/src/kamyon/meshes/kamyon_sasi.STL
cad_files/prototype_cad_files/STEP/47-boom.STEP
cad_files/ros_cad_files/Exca-1/STEP/dummy_link.STEP
cad_files/prototype_cad_files/STEP/1-lower-chassic.STEP
cad_files/prototype_cad_files/STEP/10-track_closed.STEP
cad_files/prototype_cad_files/STEP/10-track_opened.STEP
cad_files/prototype_cad_files/STEP/2-left-track-support.STEP
cad_files/prototype_cad_files/STEP/21-upper-chassic.STEP
cad_files/prototype_cad_files/STEP/22-chassic-boom-holder.STEP
cad_files/prototype_cad_files/STEP/23-boom-rotator-cuff.STEP
cad_files/prototype_cad_files/STEP/25-rear-cover.STEP
cad_files/prototype_cad_files/STEP/3-right-track-support.STEP
cad_files/prototype_cad_files/STEP/4-power-gear.STEP
cad_files/prototype_cad_files/STEP/42-boom-arm-push-rod.STEP
cad_files/prototype_cad_files/STEP/44-arm-bucket-push-rod.STEP
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

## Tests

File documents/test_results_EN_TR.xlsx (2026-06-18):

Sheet: Analysis - EN
Autonomous Excavator Test Analysis
Average Time: |  | 4:09:00
Max Time: |  | 5:44:00
Min Time: |  | 3:13:00
Test Number | Result | Failure Reason | Cycle Completion Time
1 | Success | -- | 4:34
2 | Success | -- | 4:22
3 | Success | -- | 4:02
4 | Failure | Dynamic Stop During Excavation | --
5 | Success | -- | 4:09
6 | Success | -- | 4:13
7 | Success | -- | 3:50
8 | Success | -- | 4:13
9 | Success | -- | 4:16
10 | Success | -- | 4:29
11 | Success | -- | 4:19
12 | Success | -- | 4:19
13 | Success | -- | 3:55
14 | Failure | Excavation Initialization Error | --
15 | Success | -- | 4:15
16 | Success | -- | 4:19
17 | Failure | Dynamic Stop During Excavation | --
18 | Success | -- | 4:27
19 | Success | -- | 4:09
20 | Success | -- | 5:29
21 | Success | -- | 4:20
22 | Success | -- | 4:04
23 | Failure | Transfer Flight Failure | --
24 | Success | -- | 3:30
25 | Success | -- | 4:27
26 | Success | -- | 3:50
27 | Success | -- | 4:24
28 | Success | -- | 4:08
29 | Failure | Excavation Initialization Error | --
30 | Success | -- | 4:02
31 | Success | -- | 3:34
32 | Success | -- | 5:36
33 | Failure | Excavation Initialization Error | --
34 | Success | -- | 3:13
35 | Success | -- | 4:19
36 | Success | -- | 3:52
37 | Success | -- | 3:37
38 | Success | -- | 3:33
39 | Success | -- | 3:54
40 | Success | -- | 3:22
41 | Failure | Excavation Initialization Error | --
42 | Failure | Transfer Flight Failure | --
43 | Success | -- | 4:27
44 | Success | -- | 3:36
45 | Success | -- | 4:03
46 | Success | -- | 3:46
47 | Success | -- | 5:44
48 | Success | -- | 4:23
49 | Success | -- | 4:01
50 | Failure | Excavation Initialization Error | --
51 | Success | -- | 3:52
52 | Success | -- | 4:22
53 | Success | -- | 4:01
54 | Success | -- | 4:13
55 | Success | -- | 4:06
56 | Failure | Excavation Initialization Error | --
57 | Success | -- | 4:18
58 | Success | -- | 4:15
59 | Success | -- | 3:32
60 | Success | -- | 4:16
61 | Success | -- | 4:29
62 | Success | -- | 3:58
63 | Failure | Excavation Initialization Error | --
64 | Success | -- | 3:52
65 | Success | -- | 3:56
66 | Success | -- | 3:44
67 | Success | -- | 5:13
68 | Failure | Excavation Initialization Error | --
69 | Success | -- | 4:22
70 | Success | -- | 4:14
71 | Success | -- | 3:48
72 | Success | -- | 4:09
73 | Success | -- | 4:24
74 | Success | -- | 3:36
75 | Success | -- | 4:37
76 | Success | -- | 4:21
77 | Success | -- | 3:56
78 | Failure | Dynamic Stop During Excavation | --
79 | Success | -- | 4:11
80 | Success | -- | 4:05
81 | Failure | Dynamic Stop During Excavation | --
82 | Success | -- | 3:56
83 | Success | -- | 3:55
84 | Success | -- | 4:02
85 | Success | -- | 4:11
86 | Success | -- | 4:05
87 | Success | -- | 4:05
88 | Success | -- | 3:44
89 | Success | -- | 4:21
90 | Failure | Transfer Flight Failure | --
91 | Success | -- | 4:06
92 | Success | -- | 4:26
93 | Success | -- | 4:03
94 | Success | -- | 4:25
95 | Failure | Excavation Initialization Error | --
96 | Success | -- | 3:35
97 | Success | -- | 3:46
98 | Success | -- | 4:39
99 | Success | -- | 4:09
100 | Success | -- | 4:25

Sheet: Analiz - TR
Otonom Ekskavatör Test Analizi
Ortalama Süre: |  | 4:09:00
Maksimum Süre: |  | 5:44:00
Minimum Süre: |  | 3:13:00
Test Numarası | Sonuç | Başarısızlık Sebebi | Döngü Tamamlama Süresi
1 | Başarılı | -- | 4:34
2 | Başarılı | -- | 4:22
3 | Başarılı | -- | 4:02
4 | Başarısız | Kazı Esnası Dinamik Durma | --
5 | Başarılı | -- | 4:09
6 | Başarılı | -- | 4:13
7 | Başarılı | -- | 3:50
8 | Başarılı | -- | 4:13
9 | Başarılı | -- | 4:16
10 | Başarılı | -- | 4:29
11 | Başarılı | -- | 4:19
12 | Başarılı | -- | 4:19
13 | Başarılı | -- | 3:55
14 | Başarısız | Kazı Başlatma Hatası | --
15 | Başarılı | -- | 4:15
16 | Başarılı | -- | 4:19
17 | Başarısız | Kazı Esnası Dinamik Durma | --
18 | Başarılı | -- | 4:27
19 | Başarılı | -- | 4:09
20 | Başarılı | -- | 5:29
21 | Başarılı | -- | 4:20
22 | Başarılı | -- | 4:04
23 | Başarısız | Transfer Uçuşu Başarısızlığı | --
24 | Başarılı | -- | 3:30
25 | Başarılı | -- | 4:27
26 | Başarılı | -- | 3:50
27 | Başarılı | -- | 4:24
28 | Başarılı | -- | 4:08
29 | Başarısız | Kazı Başlatma Hatası | --
30 | Başarılı | -- | 4:02
31 | Başarılı | -- | 3:34
32 | Başarılı | -- | 5:36
33 | Başarısız | Kazı Başlatma Hatası | --
34 | Başarılı | -- | 3:13
35 | Başarılı | -- | 4:19
36 | Başarılı | -- | 3:52
37 | Başarılı | -- | 3:37
38 | Başarılı | -- | 3:33
39 | Başarılı | -- | 3:54
40 | Başarılı | -- | 3:22
41 | Başarısız | Kazı Başlatma Hatası | --
42 | Başarısız | Transfer Uçuşu Başarısızlığı | --
43 | Başarılı | -- | 4:27
44 | Başarılı | -- | 3:36
45 | Başarılı | -- | 4:03
46 | Başarılı | -- | 3:46
47 | Başarılı | -- | 5:44
48 | Başarılı | -- | 4:23
49 | Başarılı | -- | 4:01
50 | Başarısız | Kazı Başlatma Hatası | --
51 | Başarılı | -- | 3:52
52 | Başarılı | -- | 4:22
53 | Başarılı | -- | 4:01
54 | Başarılı | -- | 4:13
55 | Başarılı | -- | 4:06
56 | Başarısız | Kazı Başlatma Hatası | --
57 | Başarılı | -- | 4:18
58 | Başarılı | -- | 4:15
59 | Başarılı | -- | 3:32
60 | Başarılı | -- | 4:16
61 | Başarılı | -- | 4:29
62 | Başarılı | -- | 3:58
63 | Başarısız | Kazı Başlatma Hatası | --
64 | Başarılı | -- | 3:52
65 | Başarılı | -- | 3:56
66 | Başarılı | -- | 3:44
67 | Başarılı | -- | 5:13
68 | Başarısız | Kazı Başlatma Hatası | --
69 | Başarılı | -- | 4:22
70 | Başarılı | -- | 4:14
71 | Başarılı | -- | 3:48
72 | Başarılı | -- | 4:09
73 | Başarılı | -- | 4:24
74 | Başarılı | -- | 3:36
75 | Başarılı | -- | 4:37
76 | Başarılı | -- | 4:21
77 | Başarılı | -- | 3:56
78 | Başarısız | Kazı Esnası Dinamik Durma | --
79 | Başarılı | -- | 4:11
80 | Başarılı | -- | 4:05
81 | Başarısız | Kazı Esnası Dinamik Durma | --
82 | Başarılı | -- | 3:56
83 | Başarılı | -- | 3:55
84 | Başarılı | -- | 4:02
85 | Başarılı | -- | 4:11
86 | Başarılı | -- | 4:05
87 | Başarılı | -- | 4:05
88 | Başarılı | -- | 3:44
89 | Başarılı | -- | 4:21
90 | Başarısız | Transfer Uçuşu Başarısızlığı | --
91 | Başarılı | -- | 4:06
92 | Başarılı | -- | 4:26
93 | Başarılı | -- | 4:03
94 | Başarılı | -- | 4:25
95 | Başarısız | Kazı Başlatma Hatası | --
96 | Başarılı | -- | 3:35
97 | Başarılı | -- | 3:46
98 | Başarılı | -- | 4:39
99 | Başarılı | -- | 4:09
100 | Başarılı | -- | 4:25

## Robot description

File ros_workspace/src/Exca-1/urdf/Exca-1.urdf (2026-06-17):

<?xml version="1.0" encoding="utf-8"?>
<robot name="Exca-1">
  <link name="base_link">
    <inertial>
      <origin xyz="-0.00093629 -7.0372E-16 0.067491" rpy="0 0 0" />
      <mass value="37.697" />
      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
    </inertial>
    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
  </link>

  <link name="link_1">
    <inertial>
      <origin xyz="-0.16895 -1.1137E-15 0.081554" rpy="0 0 0" />
      <mass value="26.764" />
      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
    </inertial>
    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
  </link>

  <joint name="joint_1" type="continuous">
    <origin xyz="0 0 0.11304" rpy="0 0 0" />
    <parent link="base_link" />
    <child link="link_1" />
    <axis xyz="0 0 1" />
    <limit effort="1000" velocity="1" />
  </joint>

  <link name="link_2">
    <inertial>
      <origin xyz="0.30458 0.073788 1.4816E-14" rpy="0 0 0" />
      <mass value="6.2624" />
      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
    </inertial>
    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
  </link>

  <joint name="joint_2" type="revolute">
    <origin xyz="0.07 0 0.115" rpy="1.5708 -1.2217 0" />
    <parent link="link_1" />
    <child link="link_2" />
    <axis xyz="0 0 1" />
    <limit lower="-1.919" upper="0" effort="1000" velocity="1" />
  </joint>

  <link name="link_3">
    <inertial>
      <origin xyz="0.1169 0.021719 1.0748E-14" rpy="0 0 0" />
      <mass value="3.0384" />
      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
    </inertial>
    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
  </link>

  <joint name="joint_3" type="revolute">
    <origin xyz="0.672 0 0" rpy="0 0 -0.43633" />
    <parent link="link_2" />
    <child link="link_3" />
    <axis xyz="0 0 1" />
    <limit lower="-2.268" upper="0" effort="1000" velocity="1" />
  </joint>

  <link name="link_4">
    <inertial>
      <origin xyz="-0.019219 0.091842 9.4282E-15" rpy="0 0 0" />
      <mass value="1.1448" />
      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
    </inertial>
    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
  </link>

  <joint name="joint_4" type="revolute">
    <origin xyz="0.37548 0 0" rpy="0 0 -0.7854" />
    <parent link="link_3" />
    <child link="link_4" />
    <axis xyz="0 0 1" />
    <limit lower="-3.141" upper="0" effort="1000" velocity="1" />
  </joint>

  <link name="dummy_link">
    <inertial>
      <origin xyz="-0.0025454 -2.2832E-14 -0.0041762" rpy="0 0 0" />
      <mass value="0.0006235" />
      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
    </inertial>
    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
  </link>

  <joint name="joint_tcp" type="fixed">
    <origin xyz="0.07 0.16 0" rpy="-1.5708 0 0" />
    <parent link="link_4" />
    <child link="dummy_link" />
    <axis xyz="0 0 0" />
  </joint>

  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

  <link name="kamera_on_link">
    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
  </link>
  <joint name="kamera_on_joint" type="fixed">
    <origin xyz="0.08 0.08 0.4" rpy="0 0 0" /> <parent link="link_1" />
    <child link="kamera_on_link" />
  </joint>
  <link name="kamera_on_optical" />
  <joint name="kamera_on_optical_joint" type="fixed">
    <origin xyz="0 0 0" rpy="-1.5708 0 -1.5708" />
    <parent link="kamera_on_link" />
    <child link="kamera_on_optical" />
  </joint>

  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
  
  <link name="kamera_cukur_link">
  </link>

  <joint name="kamera_cukur_joint" type="fixed">
    <origin xyz="0.30 0.0 0.45" rpy="0 0.785 0" />
    <parent link="link_1" />
    <child link="kamera_cukur_link" />
  </joint>

  <link name="kamera_cukur_optical" />
  <joint name="kamera_cukur_optical_joint" type="fixed">
    <origin xyz="0 0 0" rpy="-1.5708 0 -1.5708" />
    <parent link="kamera_cukur_link" />
    <child link="kamera_cukur_optical" />
  </joint>

  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
</robot>

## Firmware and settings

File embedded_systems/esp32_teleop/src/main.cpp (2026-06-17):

#include <Arduino.h>
#include <Wire.h>
#include <Adafruit_PWMServoDriver.h>
#include <ps5Controller.h>

Adafruit_PWMServoDriver pwm = Adafruit_PWMServoDriver();

bool wasConnected = false;

void setup() {
  Serial.begin(115200);
  
  Wire.begin(21, 22); 
  pwm.begin();
  pwm.setPWMFreq(1000); 
  
  // Kullanılan tüm H-Bridge kanallarını güvenlik amacıyla sıfırla
  for(int i = 0; i <= 11; i++) {
    pwm.setPWM(i, 0, 0);
  }

  // DualSense MAC adresini buraya gir (kendi adresinle değiştirmeyi unutma)
  ps5.begin("E8:47:3A:51:B5:67"); 
  Serial.println("Ekskavator ESP32 Baslatildi. DualSense bekleniyor...");
}

void loop() {
  if (ps5.isConnected()) {
    
    if (!wasConnected) {
      Serial.println("\n--- DUALSENSE BAGLANDI! EKSKAVATOR AKTIF ---");
      wasConnected = true;
    }

    // =========================================================
    // 1. KULE DÖNÜŞÜ (PWM 0-1) | Sol Analog X Ekseni
    // Min: 300, Max: 3000
    // =========================================================
    int lX = ps5.LStickX();
    if (lX <= -15) { // Sol Analog Sola
      int duty = map(lX, -15, -128, 300, 3000);
      pwm.setPWM(0, 0, duty);
      pwm.setPWM(1, 0, 0);
    } 
    else if (lX >= 15) { // Sol Analog Sağa
      int duty = map(lX, 15, 127, 300, 3000);
      pwm.setPWM(0, 0, 0);
      pwm.setPWM(1, 0, duty);
    } 
    else { // Ölü bölge (Dur)
      pwm.setPWM(0, 0, 0);
      pwm.setPWM(1, 0, 0);
    }

    // =========================================================
    // 2. ARM (PWM 4-5) | Sol Analog Y Ekseni
    // Min: 1400, Max: 4095
    // =========================================================
    int lY = ps5.LStickY();
    if (lY <= -15) { // Sol Analog Aşağı
      int duty = map(lY, -15, -128, 1400, 4095);
      pwm.setPWM(4, 0, duty);
      pwm.setPWM(5, 0, 0);
    } 
    else if (lY >= 15) { // Sol Analog Yukarı
      int duty = map(lY, 15, 127, 1400, 4095);
      pwm.setPWM(4, 0, 0);
      pwm.setPWM(5, 0, duty);
    } 
    else {
      pwm.setPWM(4, 0, 0);
      pwm.setPWM(5, 0, 0);
    }

    // =========================================================
    // 3. BUCKET (PWM 6-7) | Sağ Analog Y Ekseni
    // Min: 2000, Max: 4095
    // =========================================================
    int rY = ps5.RStickY();
    if (rY <= -15) { // Sağ Analog Aşağı
      int duty = map(rY, -15, -128, 2000, 4095);
      pwm.setPWM(6, 0, duty);
      pwm.setPWM(7, 0, 0);
    } 
    else if (rY >= 15) { // Sağ Analog Yukarı
      int duty = map(rY, 15, 127, 2000, 4095);
      pwm.setPWM(6, 0, 0);
      pwm.setPWM(7, 0, duty);
    } 
    else {
      pwm.setPWM(6, 0, 0);
      pwm.setPWM(7, 0, 0);
    }

    // =========================================================
    // 4. SAĞ PALET (PWM 8-9) | R2 (İleri) ve R1 (Geri)
    // Min: 500, Max: 4095
    // =========================================================
    int r2Val = ps5.R2Value(); // 0 ile 255 arası değer döner
    bool r1Pressed = ps5.R1(); // Buton olduğu için True/False döner
    
    // Hem R1 hem R2'ye yanlışlıkla aynı anda basılırsa motoru korumak için öncelik atadık
    if (r2Val > 5) { // R2'ye basıldıysa (Analog İleri)
      int duty = map(r2Val, 5, 255, 500, 4095);
      pwm.setPWM(8, 0, duty);
      pwm.setPWM(9, 0, 0);
    } 
    else if (r1Pressed) { // R1'e basıldıysa (Dijital Geri)
      pwm.setPWM(8, 0, 0);
      pwm.setPWM(9, 0, 4095); // Geri giderken sabit maksimum güç
    } 
    else {
      pwm.setPWM(8, 0, 0);
      pwm.setPWM(9, 0, 0);
    }

    // =========================================================
    // 5. SOL PALET (PWM 10-11) | L2 (İleri) ve L1 (Geri)
    // Min: 500, Max: 4095
    // =========================================================
    int l2Val = ps5.L2Value(); 
    bool l1Pressed = ps5.L1(); 
    
    if (l2Val > 5) { // L2'ye basıldıysa (Analog İleri)
      int duty = map(l2Val, 5, 255, 500, 4095);
      pwm.setPWM(10, 0, duty);
      pwm.setPWM(11, 0, 0);
    } 
    else if (l1Pressed) { // L1'e basıldıysa (Dijital Geri)
      pwm.setPWM(10, 0, 0);
      pwm.setPWM(11, 0, 4095); // Geri giderken sabit maksimum güç
    } 
    else {
      pwm.setPWM(10, 0, 0);
      pwm.setPWM(11, 0, 0);
    }
    
  } 
  else {
    // Bağlantı koparsa tüm motorları acil durdur
    if (wasConnected) {
      Serial.println("\n!!! DUALSENSE BAGLANTISI KOPTU - MOTORLAR DURDURULUYOR !!!");
      wasConnected = false;
      for(int i = 0; i <= 11; i++) {
        pwm.setPWM(i, 0, 0);
      }
    }
  }
  
  delay(15); // I2C hattını ve ESP'yi rahatlatmak için küçük gecikme
}

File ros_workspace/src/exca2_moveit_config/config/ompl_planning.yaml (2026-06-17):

planner_configs:
  AnytimePathShortening:
    type: geometric::AnytimePathShortening
    shortcut: true  # Attempt to shortcut all new solution paths
    hybridize: true  # Compute hybrid solution trajectories
    max_hybrid_paths: 24  # Number of hybrid paths generated per iteration
    num_planners: 4  # The number of default planners to use for planning
    planners: ""  # A comma-separated list of planner types (e.g., "PRM,EST,RRTConnect"Optionally, planner parameters can be passed to change the default:"PRM[max_nearest_neighbors=5],EST[goal_bias=.5],RRT[range=10. goal_bias=.1]"
  SBL:
    type: geometric::SBL
    range: 0.0  # Max motion added to tree. ==> maxDistance_ default: 0.0, if 0.0, set on setup()
  EST:
    type: geometric::EST
    range: 0.0  # Max motion added to tree. ==> maxDistance_ default: 0.0, if 0.0 setup()
    goal_bias: 0.05  # When close to goal select goal, with this probability. default: 0.05
  LBKPIECE:
    type: geometric::LBKPIECE
    range: 0.0  # Max motion added to tree. ==> maxDistance_ default: 0.0, if 0.0, set on setup()
    border_fraction: 0.9  # Fraction of time focused on boarder default: 0.9
    min_valid_path_fraction: 0.5  # Accept partially valid moves above fraction. default: 0.5
  BKPIECE:
    type: geometric::BKPIECE
    range: 0.0  # Max motion added to tree. ==> maxDistance_ default: 0.0, if 0.0, set on setup()
    border_fraction: 0.9  # Fraction of time focused on boarder default: 0.9
    failed_expansion_score_factor: 0.5  # When extending motion fails, scale score by factor. default: 0.5
    min_valid_path_fraction: 0.5  # Accept partially valid moves above fraction. default: 0.5
  KPIECE:
    type: geometric::KPIECE
    range: 0.0  # Max motion added to tree. ==> maxDistance_ default: 0.0, if 0.0, set on setup()
    goal_bias: 0.05  # When close to goal select goal, with this probability. default: 0.05
    border_fraction: 0.9  # Fraction of time focused on boarder default: 0.9 (0.0,1.]
    failed_expansion_score_factor: 0.5  # When extending motion fails, scale score by factor. default: 0.5
    min_valid_path_fraction: 0.5  # Accept partially valid moves above fraction. default: 0.5
  RRT:
    type: geometric::RRT
    range: 0.0  # Max motion added to tree. ==> maxDistance_ default: 0.0, if 0.0, set on setup()
    goal_bias: 0.05  # When close to goal select goal, with this probability? default: 0.05
  RRTConnect:
    type: geometric::RRTConnect
    range: 0.0  # Max motion added to tree. ==> maxDistance_ default: 0.0, if 0.0, set on setup()
  RRTstar:
    type: geometric::RRTstar
    range: 0.0  # Max motion added to tree. ==> maxDistance_ default: 0.0, if 0.0, set on setup()
    goal_bias: 0.05  # When close to goal select goal, with this probability? default: 0.05
    delay_collision_checking: 1  # Stop collision checking as soon as C-free parent found. default 1
  TRRT:
    type: geometric::TRRT
    range: 0.0  # Max motion added to tree. ==> maxDistance_ default: 0.0, if 0.0, set on setup()
    goal_bias: 0.05  # When close to goal select goal, with this probability? default: 0.05
    max_states_failed: 10  # when to start increasing temp. default: 10
    temp_change_factor: 2.0  # how much to increase or decrease temp. default: 2.0
    min_temperature: 10e-10  # lower limit of temp change. default: 10e-10
    init_temperature: 10e-6  # initial temperature. default: 10e-6
    frontier_threshold: 0.0  # dist new state to nearest neighbor to disqualify as frontier. default: 0.0 set in setup()
    frontier_node_ratio: 0.1  # 1/10, or 1 nonfrontier for every 10 frontier. default: 0.1
    k_constant: 0.0  # value used to normalize expresssion. default: 0.0 set in setup()
  PRM:
    type: geometric::PRM
    max_nearest_neighbors: 10  # use k nearest neighbors. default: 10
  PRMstar:
    type: geometric::PRMstar
  FMT:
    type: geometric::FMT
    num_samples: 1000  # number of states that the planner should sample. default: 1000
    radius_multiplier: 1.1  # multiplier used for the nearest neighbors search radius. default: 1.1
    nearest_k: 1  # use Knearest strategy. default: 1
    cache_cc: 1  # use collision checking cache. default: 1
    heuristics: 0  # activate cost to go heuristics. default: 0
    extended_fmt: 1  # activate the extended FMT*: adding new samples if planner does not finish successfully. default: 1
  BFMT:
    type: geometric::BFMT
    num_samples: 1000  # number of states that the planner should sample. default: 1000
    radius_multiplier: 1.0  # multiplier used for the nearest neighbors search radius. default: 1.0
    nearest_k: 1  # use the Knearest strategy. default: 1
    balanced: 0  # exploration strategy: balanced true expands one tree every iteration. False will select the tree with lowest maximum cost to go. default: 1
    optimality: 1  # termination strategy: optimality true finishes when the best possible path is found. Otherwise, the algorithm will finish when the first feasible path is found. default: 1
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

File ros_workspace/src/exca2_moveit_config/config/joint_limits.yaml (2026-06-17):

# joint_limits.yaml allows the dynamics properties specified in the URDF to be overwritten or augmented as needed

# For beginners, we downscale velocity and acceleration limits.
# You can always specify higher scaling factors (<= 1.0) in your motion requests.  # Increase the values below to 1.0 to always move at maximum speed.
default_velocity_scaling_factor: 0.7
default_acceleration_scaling_factor: 0.7

# Specific joint properties can be changed with the keys [max_position, min_position, max_velocity, max_acceleration]
# Joint limits can be turned off with [has_velocity_limits, has_acceleration_limits]
joint_limits:
  joint_1:
    has_velocity_limits: true
    max_velocity: 1
    has_acceleration_limits: false
    max_acceleration: 0
  joint_2:
    has_velocity_limits: true
    max_velocity: 1
    has_acceleration_limits: false
    max_acceleration: 0
  joint_3:
    has_velocity_limits: true
    max_velocity: 1
    has_acceleration_limits: false
    max_acceleration: 0
  joint_4:
    has_velocity_limits: true
    max_velocity: 1
    has_acceleration_limits: false
    max_acceleration: 0

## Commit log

2026-06-17 Initial commit: ROS Workspace, CAD files, Embedded System
    [1-lower-chassic.STEP, 1-lower-chassic.stl, 10-track_closed.STEP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]
2026-06-18 Adding Results and Senior Documents
    [test_results_EN_TR.xlsx]
